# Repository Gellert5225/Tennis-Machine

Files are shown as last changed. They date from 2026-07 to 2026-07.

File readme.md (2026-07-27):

# Tennis Ball Machine — Firmware

Firmware for a DIY 3D-printed tennis ball machine. An ESP32 drives two
brushless flywheels (speed and spin), a servo feed gate, an optional tilt
servo (height), and a stepper turntable (left/right placement). Control is
over WiFi — a web UI served by the board, with the same REST endpoints
available to any client.

No Raspberry Pi. No Arduino IDE. Built and flashed entirely from the
command line with PlatformIO, so it works from any editor.

---

## Hardware summary

| Subsystem | Parts | Controls |
|---|---|---|
| Launch | 2× brushless motors + 2× 40A ESCs | ball speed, topspin/backspin |
| Feed | MG996R servo gate | rate of fire |
| Oscillation | NEMA 17 + DRV8825 on a turntable | left / right / random / sweep |
| Height | MG996R tilt servo (optional) | trajectory |
| Brain | ESP32 (ESP-WROOM-32) | everything |
| Power | 4S LiPo 14.8V → UBEC → 5V logic | — |

Wheels are stacked **vertically**: top wheel faster gives backspin, bottom
wheel faster gives topspin, equal speeds gives a flat ball.

Full electrical detail lives in the wiring reference; mechanical assembly
lives in the build guide. This README covers software only.

### Pin map

Mirrors `include/config.h`, which is the single source of truth.

| Signal | GPIO |
|---|---|
| ESC 1 throttle (top wheel) | 25 |
| ESC 2 throttle (bottom wheel) | 26 |
| Feed servo | 27 |
| Tilt servo | 14 |
| Stepper STEP | 32 |
| Stepper DIR | 33 |
| Stepper EN | 13 |
| DRV8825 VDD | 3V3 |

Avoid GPIO 6–11 (flash). GPIO 34–39 are input-only.

---

## Prerequisites

**PlatformIO Core** (no IDE extension required):

```bash
pip install platformio
pio --version
```

If `pio` is not found after installing via the VS Code extension, it lives
in its own virtualenv:

```bash
export PATH="$HOME/.platformio/penv/bin:$PATH"
```

**USB driver.** Most ESP-WROOM-32 boards use a CP210x or CH340 bridge.
macOS 12+ and Windows 11 both need the vendor driver installed manually.
Confirm the board enumerates before building:

```bash
pio device list
```

You want a `/dev/cu.usbserial-*` (macOS) or `COMx` (Windows) entry. If
nothing appears, suspect a charge-only USB cable before anything else.

---

## Layout

```
.
├── platformio.ini          build targets and pinned dependencies
├── include/
│   └── config.h            pin map — single source of truth
├── src/
│   └── main.cpp            wiring-up only, kept thin
├── lib/
│   ├── drills/             PURE LOGIC — no Arduino headers
│   │   ├── ShotCommand.h
│   │   └── DrillSequencer.{h,cpp}
│   └── hal/                HARDWARE — the only place that touches pins
│       ├── ILauncher.h
│       ├── EscLauncher.cpp
│       ├── FeedGate.cpp
│       ├── Tilt.cpp
│       └── Turntable.cpp
├── test/
│   ├── test_drills/        runs on your machine
│   └── test_hardware/      runs on the board
└── .github/workflows/ci.yml
```

### The one architectural rule

`lib/drills/` must not include `<Arduino.h>`.

Drill sequencing, spin-to-throttle mapping, random placement within bounds,
and JSON parsing are plain C++ with no hardware in them. Keeping them
framework-free means they compile for your laptop, so tests run in seconds
in CI without an ESP32 attached to a build server.

`lib/hal/` is the only code that touches pins. The logic depends on the
`ILauncher` interface rather than a concrete driver, so tests substitute a
fake and assert on what the sequencer *commanded*.

---

## Commands

### Build

```bash
pio run                      # default env (esp32dev)
pio run -e esp32dev          # explicit
pio run -t clean             # clean
```

First build downloads the toolchain — a few hundred MB, several minutes.
Later builds take seconds.

### Upload

```bash
pio run -e esp32dev -t upload
```

Port is auto-detected. To force one:

```bash
pio run -e esp32dev -t upload --upload-port /dev/cu.usbserial-0001
```

If it stalls at `Connecting....`, hold the **BOOT** button until writing
starts. Some boards do not auto-reset into the bootloader.

### Serial monitor

```bash
pio device monitor           # baud comes from platformio.ini
```

`Ctrl+C` to exit. Only one program may hold the port — close any other
monitor first.

### Test

```bash
pio test -e native           # host-side logic tests, fast
pio test -e esp32dev         # on-device tests, needs the board connected
```

`native` is a **test** environment. `pio run -e native` is not meaningful
and will fail; use `pio test`.

### Editor intelligence

Generates `compile_commands.json` for clangd, so vim, emacs, or any
LSP-aware editor gets completion and diagnostics:

```bash
pio run -t compiledb
```

### Over-the-air upload

Commented out in `platformio.ini` until the machine is on the network and
running ArduinoOTA. Once it is, uncomment `[env:esp32dev_ota]` and:

```bash
pio run -e esp32dev_ota -t upload
```

---

## Control API

A drill is a sequence of shots. One shot:

```json
{ "angle": -15, "tilt": 30, "speed": 0.7, "spin": -0.3, "delay": 3.0 }
```

| Field | Meaning |
|---|---|
| `angle` | turntable position in degrees, negative is left |
| `tilt` | height servo in degrees |
| `speed` | wheel throttle, 0.0–1.0 |
| `spin` | wheel differential, −1.0 backspin … +1.0 topspin |
| `delay` | seconds until the next ball |

Endpoints: `POST /shot`, `POST /drill`, `POST /stop`, `GET /status`.

Test them with curl before writing any client:

```bash
curl -X POST http://192.168.4.1/shot \
  -H 'Content-Type: application/json' \
  -d '{"angle":0,"tilt":30,"speed":0.5,"spin":0.2,"delay":3.0}'
```

WiFi boots dual-mode: joins a known network if present, otherwise hosts its
own access point so the machine works on any court.

---

## CI

`.github/workflows/ci.yml` runs on every push:

1. `pio test -e native` — logic tests
2. `pio check -e esp32dev` — static analysis
3. `pio run -e esp32dev` — build
4. uploads `firmware.bin` as an artifact

Same commands you run locally, so a green local build means a green CI run.

---

## Firmware safety rules

These are requirements, not preferences. The machine throws balls at speed
using wheels spinning near 15,000 RPM.

- **Min throttle at boot, unconditionally.** ESCs arm on a low signal. A
  reset, brownout, or OTA reboot must never spin the wheels up.
- **Gate OTA behind a disarmed check.** OTA triggers a reboot; that reboot
  has to be boring every single time.
- **`POST /stop` must cut throttle before anything else**, then stop the
  feed.
- **Never treat software as the primary kill.** The master switch is the
  hardware stop and always wins.
- **Ramp throttle rather than stepping it.** Reduces inrush current — which
  protects the 40A fuse — and reduces mechanical shock on the wheels.

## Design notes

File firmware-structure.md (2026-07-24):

# Firmware project structure

```
tennis-ball-machine/
├── platformio.ini              build targets + pinned deps
├── include/
│   └── config.h                PIN MAP — single source of truth,
│                               mirrors the wiring reference doc
├── src/
│   └── main.cpp                thin: wire things together, then loop()
├── lib/
│   ├── drills/                 PURE LOGIC — no Arduino headers
│   │   ├── ShotCommand.h       {angle, tilt, speed, spin, delay}
│   │   ├── DrillSequencer.h    steps through a drill, decides next shot
│   │   └── DrillSequencer.cpp
│   └── hal/                    HARDWARE — talks to real pins
│       ├── ILauncher.h         interface the logic depends on
│       ├── EscLauncher.cpp     two ESCs, speed + spin
│       ├── FeedGate.cpp        SV1
│       ├── Tilt.cpp            SV2
│       └── Turntable.cpp       NEMA 17 via DRV8825
├── test/
│   ├── test_drills/            runs on your Mac (pio test -e native)
│   └── test_hardware/          runs on the board (pio test -e esp32dev)
└── .github/workflows/ci.yml
```

## The one rule that makes this testable

`lib/drills/` must not `#include <Arduino.h>`.

Drill sequencing, spin-to-throttle mapping, random placement within
bounds, and JSON parsing are all plain C++ with no hardware in them.
Keep them hardware-free and they compile for your laptop, so CI can
test them in seconds without an ESP32 plugged into a build server.

`lib/hal/` is the only place that touches pins. The logic depends on
an interface (`ILauncher`), not on `EscLauncher` directly — so tests
substitute a fake and assert on what the sequencer *commanded* rather
than needing a motor to spin.

## What CI actually catches

- drill logic regressions (host tests, seconds)
- code that no longer compiles for ESP32
- static analysis defects
- and it hands you a flashable `firmware.bin` per commit

## CD = OTA

`pio run -e esp32dev_ota -t upload` pushes firmware over WiFi. The
machine already has WiFi for its control UI, so deployment is free.

SAFETY: gate OTA behind an "motors disarmed" check in firmware, and
keep min-throttle-at-boot unconditional. A reboot mid-session must
never spin the wheels.

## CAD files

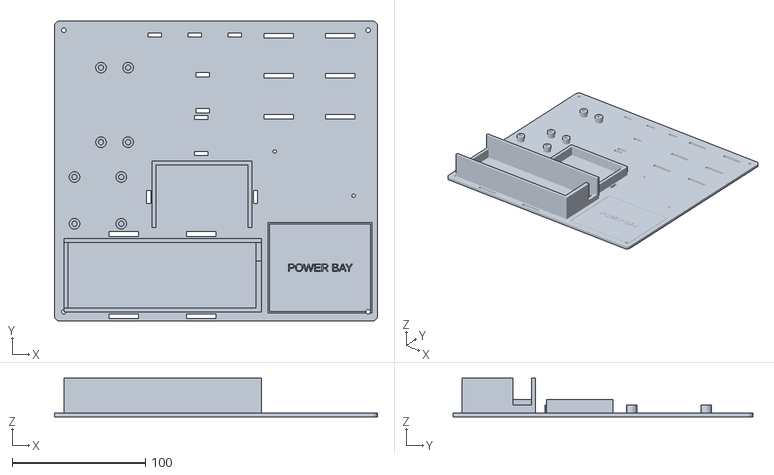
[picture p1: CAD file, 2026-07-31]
assets/testbench-tray.stl
242.0 x 225.0 x 29.0

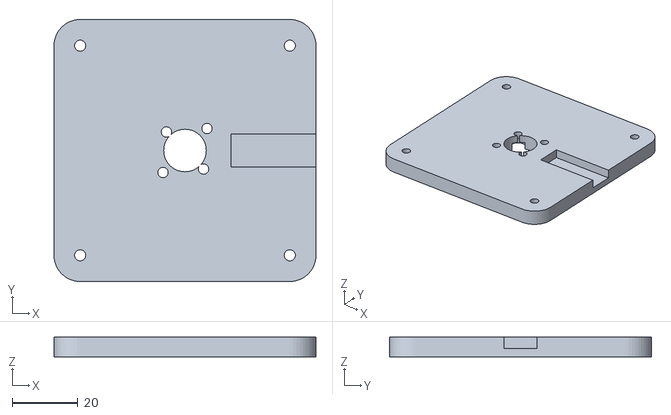
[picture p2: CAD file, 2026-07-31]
assets/spin-stand.stl
80.0 x 80.0 x 6.00

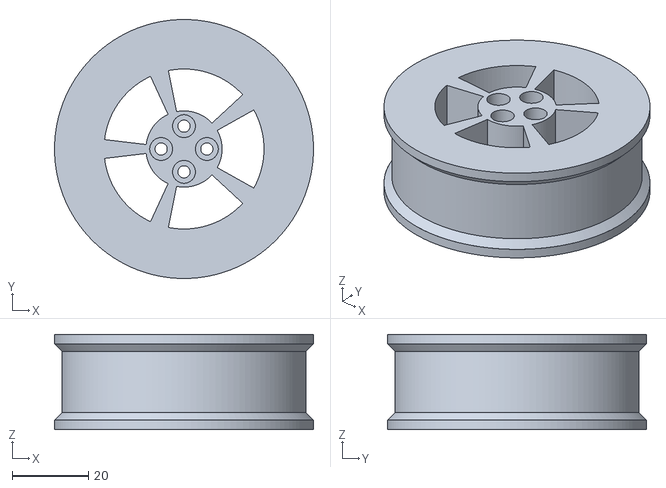
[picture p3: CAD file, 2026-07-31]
assets/flywheel.stl
68.0 x 68.0 x 25.0

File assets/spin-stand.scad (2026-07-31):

// ===========================================================
//  SPIN STAND — minimal motor pedestal for flywheel testing.
//  Print TWO. Not a launch fixture: no gap, no ball — just a
//  safe, stable place for a motor + cup wheel to spin and live
//  during development.
//
//  Motor axis VERTICAL (wheel horizontal): most stable posture,
//  symmetric vibration, low CG. Motor bolts from BELOW with
//  M3x10 + washers — heads hide in the clearance the TPU feet
//  create (dock-kit pucks push into the corner holes; corners
//  also take screws if you'd rather bolt it to a board).
//
//  The cup wheel spins 2.5 mm above the deck — keep it clean —
//  and the phase wires lie in the recessed channel until past
//  the wheel's shadow, where the bullets have full height.
//
//  PRINT: PETG, 0.28 draft, 2-3 walls, 15%, no supports,
//  ~50 min each.  First spins: low throttle, hand or clamp on
//  the plate until you trust it.
// ===========================================================

sz = 80;  t = 4;
motor_dx = 16;  motor_dy = 19;    // MEASURED 5010 base cross
center_hole = 13;
groove_w = 8;  groove_d = 3.5;    // wire channel
corner_hole = 3.4;                // TPU feet or screw-down
$fn = 48;

difference() {
    // rounded plate
    hull() for (x = [-1, 1]) for (y = [-1, 1])
        translate([x*(sz/2 - 8), y*(sz/2 - 8), 0])
            cylinder(r = 8, h = t);

    // motor cross at -45°: the wires exit 45° between the arms —
    // chirality fixed from the bench (bottom view: long-pitch hole
    // sits to the wire's LEFT), so MINUS 45 aims the exit down the
    // +x channel. If a motor's exit mirrors, flip it 180° on the
    // same holes. Counterbored screws keep the bottom flush.
    rotate([0, 0, -45])
        for (p = [[-motor_dx/2, 0], [motor_dx/2, 0],
                  [0, -motor_dy/2], [0, motor_dy/2]]) {
            translate([p[0], p[1], -1]) cylinder(d = 3.2, h = t + 2);
            translate([p[0], p[1], -1]) cylinder(d = 6.5, h = 4);   // head + washer
        }
    translate([0, 0, -1]) cylinder(d = center_hole, h = t + 2);

    // wire channel: widened + earlier mouth, since the wires root a
    // few mm to one side of the long-axis hole
    translate([14, -(groove_w + 2)/2, t - groove_d])
        cube([sz/2 - 14 + 1, groove_w + 2, groove_d + 1]);

    // corner holes
    for (x = [-1, 1]) for (y = [-1, 1])
        translate([x*(sz/2 - 8), y*(sz/2 - 8), -1])
            cylinder(d = corner_hole, h = t + 2);
}

// ghosts: motor + cup wheel (band starts 2.5 above the deck)
%translate([0, 0, t]) cylinder(d = 50, h = 12.5);
%translate([0, 0, t + 2.5]) cylinder(d = 64, h = 25);
%color("darkorange", 0.5) translate([0, 0, t + 5])
    difference() { cylinder(d = 80, h = 20);
                   translate([0,0,-1]) cylinder(d = 64, h = 22); }

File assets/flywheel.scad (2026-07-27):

// ===========================================================
//  Tennis ball machine — flywheel (hub + tire)
//  Vertical-stack topspin configuration
//
//  Each wheel = 1x hub (PETG) + 1x tire (TPU 95A)
//  You need TWO of each: top wheel and bottom wheel.
//
//  Open in OpenSCAD (free). Edit the parameters below,
//  press F5 to preview, F6 to render, then export STL.
// ===========================================================

// ---------- WHAT TO PRINT ----------
// "hub"  = rigid PETG part that bolts to the motor rotor (extruded style)
// "cup"  = shroud-style hub wrapping the rotor — same tire + same bolts
// "tire" = flexible TPU ring that grips the ball
// "assembly" = preview only, do not export
part = "cup";   // ["hub", "cup", "tire", "assembly"]


// ---------- CUP HUB (part = "cup") ----------
// Shroud alternative: the wheel wraps the ø50 rotor instead of standing
// on top of it. Tire seat and bolt pattern are IDENTICAL to the hub, so
// printed tires fit either and the two designs can be A/B tested on the
// same motor. Top-face vents MATCH the rotor's 5-window pattern; cup and
// rotor co-rotate, so window alignment is fixed at assembly — try all
// four bolt orientations and keep the best overlap (4-fold bolts vs
// 5-fold vents can sit up to 18° off; worst case still ~70% open).
motor_rotor_od = 50;    // MEASURED: rotor can diameter
skirt_clear    = 0.25;  // radial gap to the can (it co-rotates — this gap
                        //   is print tolerance, not rub protection)
skirt_depth    = 13;    // Can depth measured ~12.5 (rough): skirt stops
                        //   2.5 mm above the spinning-to-stationary seam.
                        //   Formula: skirt_depth = can_depth − 2 (tighten
                        //   the margin only after a precise can measure).
                        //   To go DEEPER than the seam later: confirm the
                        //   base OD is smaller than the can, and give A3
                        //   a wire groove under the rim.
vent_count     = 5;     // matches the rotor windows
vent_spoke     = 3.65;  // MEASURED: spoke width between rotor windows
vent_r_out     = 21;    // MEASURED: windows end 4 mm in from the ø50 wall
vent_r_in      = 10;    // MEASURE: radius where the rotor's centre disc
                        //   ends and its windows begin


// ---------- MOTOR MOUNT: 5010 PANCAKE, ROTOR-TOP BOLTS ----------
// JeeFly 5010 750KV. The rotor top carries 4x M3 threaded holes; the
// hub bolts straight on with M3x12 from the assortment. Values below
// come from the GoolRC 5010 family sheet — VERIFY the three marked
// numbers against the JeeFly listing drawing before printing.
rotor_bolt_circle = 12;   // VERIFY: rotor-top hole circle diameter
rotor_hole_count  = 4;
rotor_hole_dia    = 3.2;  // M3 clearance
rotor_stub_dia    = 5;    // MEASURED: a ø3 shaft stub protrudes at the rotor
rotor_stub_depth  = 6;    //   centre. ø5 x 6 pocket swallows it with margin.
                          //   Geometry sanity: pocket wall to screw-hole edge
                          //   = 1.9 mm; and the pocket lives in the hub's
                          //   inner 8 mm while the counterbores occupy the
                          //   outer 17 mm — they never meet in Z, so the
                          //   centre-zone crowding class is impossible here.
                          //   If the stub is TALLER than ~5 mm, flag it
                          //   BEFORE printing (relief strategy changes).
cbore_dia         = 6.0;  // clears an M3 socket head (ø5.5) + driver
cbore_depth       = 17;   // TUNED for M3x12: engages ~4 mm of rotor thread
                          // without poking past the rotor plate into the
                          // windings. If you change screw length:
                          // cbore_depth = wheel_width - (screw_len - 4)


// ---------- BALL + PINCH GEOMETRY ----------
ball_dia   = 67;   // regulation tennis ball
pinch_gap  = 60;   // surface-to-surface gap between the two tires
                   //   67 = no grip, 55 = very aggressive
                   //   60 gives 3.5 mm compression per side. Start here.

// ---------- WHEEL SIZE ----------
wheel_od   = 80;   // outer diameter of the finished wheel (tire surface)
wheel_width = 25;  // how wide the wheel is
tire_thick = 8;    // radial thickness of the TPU tire


// ---------- FIT / TOLERANCE ----------
tire_squeeze = 0.50;  // tire ID is undersized by this so it stretches on
flange_thick = 2.5;   // side lips that stop the tire walking off
tread_serrations = 48; // axial V-grooves across the tread — edges bite the
                       //   felt in the drive direction. 0 = smooth tread.
serration_depth  = 0.6;

$fn = 120;


// ===========================================================
//  DERIVED — do not edit
// ===========================================================
hub_od      = wheel_od - 2*tire_thick;   // tire seats on this
flange_od   = hub_od + 4;                // must stay clear of the ball
chamfer_h   = (flange_od - hub_od)/2;    // 45° self-supporting transition
tire_id     = hub_od - tire_squeeze;
tire_width  = wheel_width - 2*flange_thick;
motor_pitch = wheel_od + pinch_gap;      // motor centre-to-centre spacing
ball_squash = (ball_dia - pinch_gap) / 2;

// cup derivations
disc_t          = wheel_width - skirt_depth;   // solid top section of the cup
vent_arc        = 360/vent_count
                  - (vent_spoke / ((vent_r_in + vent_r_out)/2)) * 180/PI;
cup_cbore_depth = disc_t - 8;                  // M3x12 -> ~4 mm engagement

echo(str("Hub OD .................. ", hub_od, " mm"));
echo(str("Tire ID (print this) .... ", tire_id, " mm"));
echo(str("Tire width .............. ", tire_width, " mm"));
echo(str("Ball compression/side ... ", ball_squash, " mm"));
echo(str("Cup: disc ", disc_t, " / skirt wall ",
         (hub_od - motor_rotor_od - 2*skirt_clear)/2, " / vent arc ",
         vent_arc, " deg"));
echo(str(">>> MOTOR CENTRE SPACING  ", motor_pitch, " mm  <<<"));;


// ===========================================================
//  SHARED OUTER BODY — tire seat, flanges, chamfers
//  (identical for hub and cup, so tires interchange)
// ===========================================================
module wheel_body() {
    cylinder(d = hub_od, h = wheel_width, center = true);
    // retaining flanges
    translate([0, 0,  (wheel_width - flange_thick)/2])
        cylinder(d = flange_od, h = flange_thick, center = true);
    translate([0, 0, -(wheel_width - flange_thick)/2])
        cylinder(d = flange_od, h = flange_thick, center = true);
    // 45° chamfer cones into both flanges (the bare 90° step sagged)
    translate([0, 0, wheel_width/2 - flange_thick - chamfer_h])
        cylinder(d1 = hub_od, d2 = flange_od, h = chamfer_h + 0.01);
    translate([0, 0, -wheel_width/2 + flange_thick - 0.01])
        cylinder(d1 = flange_od, d2 = hub_od, h = chamfer_h + 0.01);
}


// ===========================================================
//  HUB  — print in PETG
// ===========================================================
module hub() {
    difference() {
        wheel_body();

        // centre relief over the rotor's shaft stub / retaining clip.
        if (rotor_stub_dia > 0)
            translate([0, 0, -wheel_width/2 - 0.1])
                cylinder(d = rotor_stub_dia, h = rotor_stub_depth + 0.1);

        // 4x M3 into the rotor-top threads, counterbored from the outer
        // face so M3x12 socket screws from the assortment reach the rotor
        for (i = [0 : rotor_hole_count - 1])
            rotate([0, 0, i * 360/rotor_hole_count])
                translate([rotor_bolt_circle/2, 0, 0]) {
                    cylinder(d = rotor_hole_dia, h = wheel_width + 10, center = true);
                    translate([0, 0, wheel_width/2 - cbore_depth])
                        cylinder(d = cbore_dia, h = cbore_depth + 5);
                }

        // lightening pockets — reduces mass and print time.
        // Symmetric, so balance is preserved.
        for (i = [0 : 5])
            rotate([0, 0, i * 60])
                translate([hub_od/4 + 2, 0, 0])
                    cylinder(d = 9, h = wheel_width + 10, center = true);
    }
}


// ===========================================================
//  CUP  — shroud-style hub, print in PETG, TOP FACE DOWN
//  (skirt opening prints upward; counterbore floors are the
//  only bridges and they're ø6 — trivial)
// ===========================================================
module cup() {
    difference() {
        wheel_body();

        // skirt bore: wraps the rotor can from the inner face up
        translate([0, 0, -wheel_width/2 - 0.1])
            cylinder(d = motor_rotor_od + 2*skirt_clear, h = skirt_depth + 0.1);

        // stub relief in the ceiling (the face that lands on the rotor)
        translate([0, 0, -wheel_width/2 + skirt_depth - 0.1])
            cylinder(d = rotor_stub_dia, h = rotor_stub_depth + 0.1);
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

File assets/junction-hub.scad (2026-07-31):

// ===========================================================
//  Junction hub — printed housing for the bench's J+ / J-
//  distribution node.
//
//  TWO CHAMBERS = two polarities. Left room: the J+ lever nut
//  and every red conductor. Right room: J- and every black.
//  The divider makes a +/- short impossible even if a wire
//  slips. Chambers hold the CONNECTORS; the comb slots hold
//  the WIRES — one doorway per conductor:
//
//    LOAD window (apron: E1 E2 UB VM): all eight load wires exit
//              here, both colors — blacks cross the open top to
//              the back nut. FEED window (apron: FEED): the feed
//              pair enters and U-turns to port 5.
//    CHAMBERS ARE POLARITY, WINDOWS ARE DIRECTION. Each nut runs
//    1 feed in + 4 loads out — that IS a distribution node.
//
//  Open top: wires drop into their slots from above, and the
//  node stays meter-able and re-leverable on the bench.
// ===========================================================

// ---------- LEVER NUT (MEASURED — the units in hand) ----------
nut_l = 29.7;    // measured 5-port span   (datasheet said 30.0)
nut_w = 18.17;   // measured wire-axis depth (datasheet 18.8)
nut_h = 8.1;     // measured height          (datasheet 8.6)
nut_clear = 0.4; // pocket clearance so printed cradles accept them
               // NOTE: all 5 ports open on ONE face — seat each nut with its
               // entry face toward the OUT comb; the single IN wire U-turns
               // through a dressing room to its port. Strip wires 11 mm.
               // (Measured port walls 1.22 end / 0.76 mid: the nut's own
               // 5.6 mm pitch spaces the wires — no comb required.)

// ---------- STRUCTURE ----------
wall     = 2.5;
divider  = 3;
floor_t  = 3;
dress    = 9;      // wire dressing room beyond each cradle end
apron    = 13;     // deck extensions carrying the zip anchors
tab_hole = 3.4;

in_w  = 2*(nut_w + nut_clear) + divider;
in_l  = nut_l + nut_clear + 2*dress;
out_w = in_w + 2*wall;
out_l = in_l + 2*wall;
comb_h = floor_t + nut_h + 4;

$fn = 36;

// one open window per wall, as wide as the nut face. A sill beam
// stays below it for stiffness; wires drop in over it.
module wall_window(y0) {
    translate([wall + dress - 1, y0 - 1, floor_t + 2])
        cube([nut_l + nut_clear + 2, wall + 2, comb_h]);
}

module hub() {
    difference() {
        cube([out_l, out_w, comb_h]);
        translate([wall, wall, floor_t])
            cube([in_l, in_w, comb_h]);
        wall_window(0);              // OUT chamber window
        wall_window(out_w - wall);   // IN chamber window

        // polarity engraved in each chamber floor, at the dressing-room
        // end so it stays visible with the nuts installed. The rooms are
        // + and -, NOT "in" and "out" — both rooms carry in AND out wires.
        translate([wall + 4.5, wall + nut_w/2, floor_t - 0.6])
            linear_extrude(1)
                text("+", size = 7, halign = "center", valign = "center");
        translate([wall + 4.5, wall + nut_w + divider + nut_w/2, floor_t - 0.6])
            linear_extrude(1)
                text("-", size = 7, halign = "center", valign = "center");
    }

    // divider between polarity chambers — rises past the nut tops
    translate([wall, wall + nut_w, floor_t])
        cube([in_l, divider, nut_h + 2]);

    // locating ribs: bracket the nuts lengthwise
    for (x = [wall + dress - 2, wall + dress + nut_l + nut_clear])
        translate([x, wall, floor_t])
            cube([2, in_w, 3]);

    // aprons with zip anchors + engraved labels
    for (side = [0, 1])
        translate([out_l/2 - 30, side == 0 ? -apron : out_w, 0])
            difference() {
                cube([60, apron, floor_t]);
                for (sx = [8, 44])
                    translate([sx, apron/2 - 5, -1])
                        cube([3.2, 10, floor_t + 2]);
                translate([30, apron/2, floor_t - 0.6])
                    linear_extrude(1)
                        text(side == 0 ? "E1 E2 UB VM" : "FEED", size = 4.5,
                             halign = "center", valign = "center");
            }

    // mount tabs, diagonal corners — the DOCK pattern. It is
    // 180°-symmetric, so the hub screws onto any matching pair of
    // ø2.6 bores in either orientation (M3x6: tab + 3 mm plate,
    // flush underneath). The bench tray carries this pattern now;
    // the enclosure floor inherits it later.
    for (p = [[-8, out_w - 10], [out_l - 2, 2]])
        translate([p[0], p[1], 0])
            difference() {
                cube([10, 8, floor_t]);
                translate([5, 4, -1]) cylinder(d = tab_hole, h = floor_t + 2);
            }
}

hub();

// ghosts: the two lever nuts in their chambers
%translate([wall + dress, wall, floor_t]) cube([nut_l, nut_w, nut_h]);
%translate([wall + dress, wall + nut_w + nut_clear + divider, floor_t]) cube([nut_l, nut_w, nut_h]);

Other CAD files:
assets/testbench-tray.scad

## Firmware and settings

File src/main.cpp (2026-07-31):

// SPIN TEST v3 — DUAL ESC for launch testing.
// ESC A (top wheel)    -> GPIO 25   ESC B (bottom wheel) -> GPIO 26
// Both servo-lead GNDs -> ESP32 GND. Reds taped, never connected.
// Flash + monitor FIRST (holds min), THEN battery switch; both ESCs beep.
//
// Commands:
//   1000..2000    BOTH motors, microseconds
//   a<us> b<us>   one motor  (a1300 = top only)
//   r<rpm>        BOTH via rpm estimate (kick-start if from standstill)
//   u / d         both +/- 25us     s or 0   STOP BOTH
//
// LAUNCH PROTOCOL (read before feeding a ball):
//   direction check at 1100 first — at the GAP both surfaces must
//   move toward the exit; wrong motor => power off, swap 2 bullets.

#include <Arduino.h>
#include <ESP32Servo.h>

constexpr int PIN_A = 25, PIN_B = 26;
constexpr int MIN_US = 1000, MAX_US = 2000, STEP_US = 25;
constexpr int KICK_US = 1300, KICK_MS = 600;
constexpr float KV = 750.0, VBATT = 15.5;

Servo escA, escB;
int thrA = MIN_US, thrB = MIN_US;

int rpmEst(int us)  { return (int)((us - 1000) / 1000.0 * KV * VBATT); }
int usForRpm(int r) { return 1000 + (int)(1000.0 * r / (KV * VBATT)); }

void apply(int a, int b) {
  thrA = constrain(a, MIN_US, MAX_US);
  thrB = constrain(b, MIN_US, MAX_US);
  escA.writeMicroseconds(thrA);
  escB.writeMicroseconds(thrB);
  Serial.printf("A %d us (~%d rpm)   B %d us (~%d rpm)\n",
                thrA, rpmEst(thrA), thrB, rpmEst(thrB));
}

void setBoth(int us) {
  us = constrain(us, MIN_US, MAX_US);
  bool standstill = (thrA == MIN_US && thrB == MIN_US);
  if (standstill && us > MIN_US && us < KICK_US) {
    Serial.printf("kick-start both: %d us for %d ms...\n", KICK_US, KICK_MS);
    escA.writeMicroseconds(KICK_US);
    escB.writeMicroseconds(KICK_US);
    delay(KICK_MS);
  }
  apply(us, us);
}

void setup() {
  Serial.begin(115200);
  escA.setPeriodHertz(50);  escA.attach(PIN_A, MIN_US, 2000);
  escB.setPeriodHertz(50);  escB.attach(PIN_B, MIN_US, 2000);
  escA.writeMicroseconds(MIN_US);
  escB.writeMicroseconds(MIN_US);
  Serial.println("holding min on BOTH — toggle the switch, wait for beeps.");
  Serial.println("us=both | a<us> | b<us> | r<rpm> | u | d | s");
}

void loop() {
  if (!Serial.available()) return;
  String cmd = Serial.readStringUntil('\n');
  cmd.trim();
  if (cmd == "s" || cmd == "0")        apply(MIN_US, MIN_US);
  else if (cmd == "u")                 apply(thrA + STEP_US, thrB + STEP_US);
  else if (cmd == "d")                 apply(thrA - STEP_US, thrB - STEP_US);
  else if (cmd.startsWith("a"))        apply(cmd.substring(1).toInt(), thrB);
  else if (cmd.startsWith("b"))        apply(thrA, cmd.substring(1).toInt());
  else if (cmd.startsWith("r"))        setBoth(usForRpm(cmd.substring(1).toInt()));
  else if (cmd.toInt() >= MIN_US)      setBoth(cmd.toInt());
  else Serial.println("us=both | a<us> | b<us> | r<rpm> | u | d | s");
}

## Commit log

2026-07-27 test script
    [flywheel.scad, flywheel_hub.3mf, flywheel_hub.stl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]
2026-07-31 test launch
    [flywheel.stl, junction-hub.scad, spin-stand.scad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]
